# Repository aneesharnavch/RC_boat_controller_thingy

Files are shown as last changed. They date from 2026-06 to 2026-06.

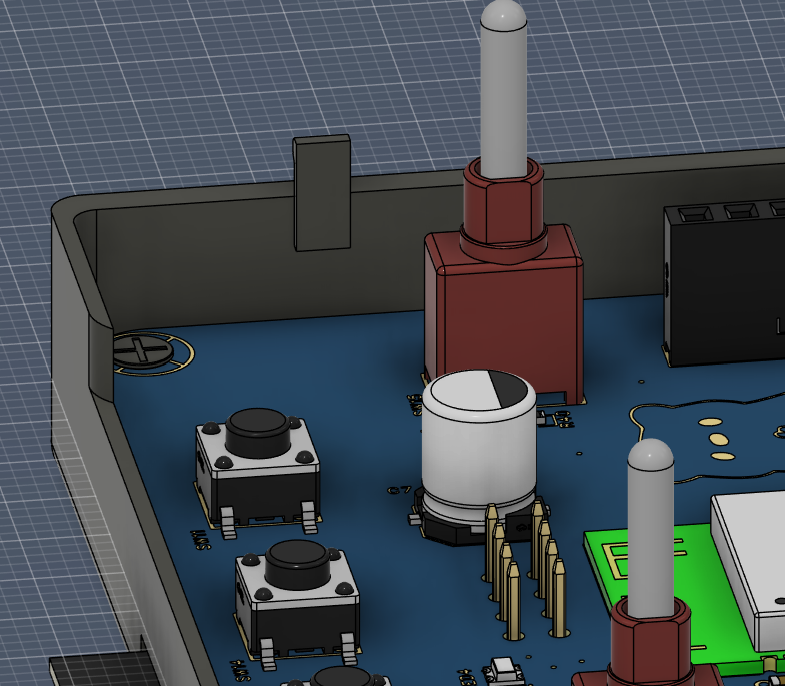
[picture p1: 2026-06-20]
Assets/controller_screw_assembly.png

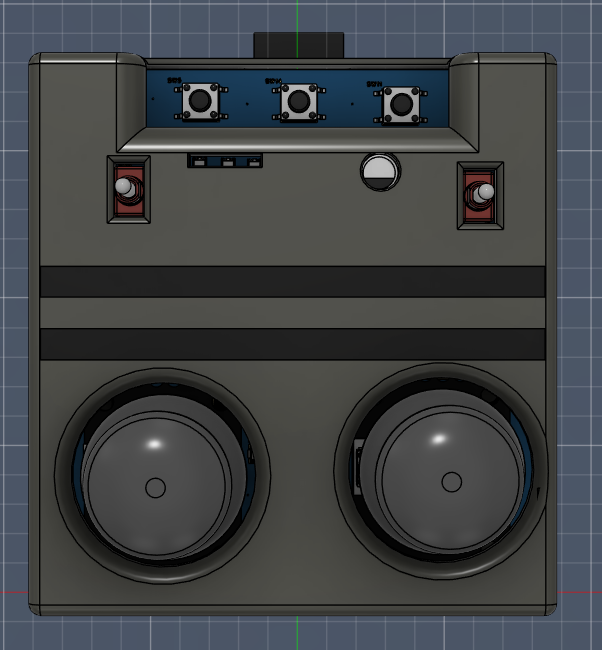
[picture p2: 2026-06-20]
Assets/controller_front.png

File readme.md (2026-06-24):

# RC Boat Thingy - an RC boat that goes WROOM WROOM   

title_pic

A Boat controller with an **IMU**, **Gyro** and **GPS** packed into a 3D-printed hull, powering an **ESC** and a **BLDC** motor. Along with it is a small controller that controls the boat over about a 2 km range.

# How does it work?

There's a simple RP2040-based controller IC that connects to all the electronics in the boat's hull. The controller then remotely connects to the receiver  and allows you to control its speed, direction, etc. When powered on and set up properly, the system works together to drive the propeller and move the boat across the water. 

# Why did I make it?

This was inspired by a boat my friends and I built back in the junior year of high school. While the initial idea we had back then worked in theory, the actual execution was.... Let's just say less successful. Because the boat we made in 2023~2024 had no Gyro with just a lacklustre IMU, its stabilisation was non-existent, with it doing WROOM WROOM underwater (thank god transparent nail polish is waterproof)

"RC Boat Thingy" is basically our second attempt at doing it properly, but approaching it with actual electronics and an actual control system, so it's actually controllable and usable without turning it into a submarine

# Components Required for the Build

| No. | Quantity | Description | Supplier | Supplier Part | Product Link | Cost | Total (USD) |
| --- | --- | --- | --- | --- | --- | --- | --- |
| 1 | 6 | 1x1 2.54mm pins for testing and troubleshooting | LCSC | C7501259 | https://www.lcsc.com/product-detail/C7501259.html | 0.015  | 0.09 |
| 2 | 1 | 1x6 2.54mm pins for connecting the ESC to the Controller | LCSC | C34498 | https://www.lcsc.com/product-detail/C34498.html | 0.51 | 0.51 |
| 3 | 1 | 1x4 2.54mm pins for SWD Branch out Header | LCSC | C2935929 | https://www.lcsc.com/product-detail/C2935929.html | 0.035  | 0.035 |
| 4 | 2 | BOOT and RESET buttons for the RP2040 | LCSC | C918859 | https://www.lcsc.com/product-detail/C918859.html | 0.2275 | 0.455 |
| 5 | 8 | 2.2uF 0603 Capacitors | LCSC | C23630 | https://www.lcsc.com/product-detail/C23630.html | 0.0093 | 0.0744 |
| 6 | 25 | 100nF 0603 Capacitors | LCSC | C191538 | https://www.lcsc.com/product-detail/C191538.html | 0.0122 | 0.305 |
| 7 | 2 | 15pF 0603 Capacitor | LCSC | C107037 | https://www.lcsc.com/product-detail/C107037.html | 0.0046 | 0.0092 |
| 8 | 1 | Antenna Connector for GPS Module | LCSC | C88374 | https://www.lcsc.com/product-detail/C88374.html | 0.108  | 0.108 |
| 9 | 1 | 33nH Inductor for GPS Antenna | LCSC | C90209 | https://www.lcsc.com/product-detail/C90209.html | 0.0134 | 0.0134 |
| 10  | 1 | LDO for RP2040 Battery to MC Power Rail | LCSC | C82942 | https://www.lcsc.com/product-detail/C82942.html | 0.51 | 0.51 |
| 11  | 1 | 0603 Red LED | LCSC | C84263 | https://www.lcsc.com/product-detail/C84263.html | 0.0095 | 0.0095 |
| 12  | 1 | 0603 Blue LED | LCSC | C965799 | https://www.lcsc.com/product-detail/C965799.html | 0.0035 | 0.0035 |
| 13  | 1 | Diode for LDO current Regulation | LCSC | C20512 | https://www.lcsc.com/product-detail/C20512.html | 0.0614 | 0.0614 |
| 14  | 5 | 1KΩ 0603 Resistor | LCSC | C22548 | https://www.lcsc.com/product-detail/C22548.html | 0.0016 | 0.008 |
| 15  | 1 | 470Ω 0603 Resistor | LCSC | C114669 | https://www.lcsc.com/product-detail/C114669.html | 0.0018 | 0.0018 |
| 16  | 1 | 200KΩ 0603 Resistor | LCSC | C105574 | https://www.lcsc.com/product-detail/C105574.html | 0.0016 | 0.0016 |
| 17  | 1 | 100KΩ 0603 Resistor | LCSC | C14675 | https://www.lcsc.com/product-detail/C14675.html | 0.0014 | 0.0014 |
| 18  | 1 | 200Ω 0603 Resistor | LCSC | C114664 | https://www.lcsc.com/product-detail/C114664.html | 0.0016 | 0.0016 |
| 19  | 1 | 1Ω 0603 Resistor | LCSC | C112305 | https://www.lcsc.com/product-detail/C112305.html | 0.0042 | 0.0042 |
| 20  | 6 | 10KΩ 0603 Resistor | LCSC | C965184 | https://www.lcsc.com/product-detail/C965184.html | 0.0032 | 0.0192 |
| 21  | 2 | 27Ω 0603 Resistor | LCSC | C25190 | https://www.lcsc.com/product-detail/C25190.html | 0.0015 | 0.003 |
| 22  | 4 | 5.1KΩ 0603 Resistor | LCSC | C23186 | https://www.lcsc.com/product-detail/C23186.html | 0.0016 | 0.0064 |
| 23  | 2 | 4.7KΩ 0603 Resistor | LCSC | C99782 | https://www.lcsc.com/product-detail/C99782.html | 0.0015 | 0.003 |
| 24  | 1 | RP2040 Microcontroller | LCSC | C2040 | https://www.lcsc.com/product-detail/C2040.html | 0.95 | 0.95 |
| 25  | 1 | W25Q128JVSIQ Flash Memory | LCSC | C97521 | https://www.lcsc.com/product-detail/C97521.html | 2.64 | 2.64 |
| 26  | 1 | 12MHz 10pF Crystal Oscillator | LCSC | C5288803 | https://www.lcsc.com/product-detail/C5288803.html | 0.59 | 0.59 |
| 27  | 1 | BMP388 Digital Pressure Sensor | LCSC | C779278 | https://www.lcsc.com/product-detail/C779278.html | 2.37 | 2.37 |
| 28  | 1 | M216Z-D80 GPS Module | LCSC | C49286686 | https://www.lcsc.com/product-detail/C49286686.html | 5.09 | 5.09 |
| 29  | 1 | USB C connector | LCSC | C2765186 | https://www.lcsc.com/product-detail/C2765186.html | 0.0704 | 0.0704 |
| 30  | 1 | RICHTEK RT9080-33GJ5(REGULARTOR FOR USB C | LCSC | C841192 | https://www.lcsc.com/product-detail/C841192.html | 0.1182 | 0.1182 |
| 31  | 1 | RED LED 0805 | LCSC | C84256 | https://www.lcsc.com/product-detail/C84256.html | 0.0134 | 0.0134 |
| 32  | 2 | BOOT AND RESET SWITCHES FOR THE CONTOLER | LCSC | C720477 | https://www.lcsc.com/product-detail/C720477.html | 0.054  | 0.108 |
| 33  | 1 | FLIP SWITCHES FOR CONTOLER | LCSC | C908284 | https://www.lcsc.com/product-detail/C908284.html | 1.664  | 1.664 |
| 34  | 3 | TACT BUTTON FOR CONTOLER | LCSC | C455118 | https://www.lcsc.com/product-detail/C455118.html | 0.0581 | 0.1743 |
| 35  | 1 | CAPASITOR FOR CONTORLER | LCSC | C72522 | https://www.lcsc.com/product-detail/C72522.html | 0.0221 | 0.0221 |
| 36  | 3 | LED for controller | LCSC | C965560 | https://www.lcsc.com/product-detail/C965560.html | 0.55 | 1.65 |
| 37  | 3 | USB C backwards current diode | LCSC | C41409280 | https://www.lcsc.com/product-detail/C41409280.html | 0.0243 | 0.0729 |
| 38  | 2 | Joystick | ElectroPi  | EPI7882 | https://www.electropi.in/dual-axis-xy-joystick-module | 0.29 | 0.58 |
| 39  | 2 | NRF24L01 Receiver and Transmitter | makerBazar | SKU:422942410 | https://makerbazar.in/products/2-4ghz-nrf24l01-pa-lna-sma-wireless-transceiver-antenna | 1.54 | 3.08 |
| 40  | 1 | IMU & Accelerometer Sensor | robu | SKU: R184320  | https://robu.in/product/icm-20948-tdk-invensense | 14.19  | 14.19 |
| 41  | 1 | Boat Controller PCB | JLCPCB | NA | https://cart.jlcpcb.com/quote | 1.3 | 1.3 |
| 42  | 1 | Transmitter PCB | JLCPCB | NA | https://cart.jlcpcb.com/quote | 1.3 | 1.3 |
| | | | | | | Total  | 38.2179 |

You can find the BOM in the repo as well!

# PCB and Schematic

I designed it in EasyEDA Pro. You can find the Gerber files in the repo. The schematic is:

The primary Boat Controller has the following schematics and PCBs:

schematic_board
pcb_board

The Transmitter has the following schematics and PCBs:

schematic_controller
pcb_controller

# Case

The Control Board is meant to be a fully tunable board with different motor control profiles based on the boat's dimensions. 

The transmitter needs its own case with its CAD files mentioned in the CAD_Files folder. 
The top and bottom view of the total transmitter assembly is attached below. 

controller_front

controller_back

controller_internal

The case features a snap-fit design, so you just have to like align the top and bottom parts of the 3D print together and press them together. You only need screws to screw the PCB into place with the bottom part.

controller_screw_assembly

# Assembly

Please do note that these assembly instructions are not final and can change. I've yet to build it, and when I do, I'll update this section to be more accurate. In the meanwhile, don't be afraid to change things up or make use of the several exposes GPIO pins/testing pad to make any modifications you would like to make. 

Note : Soldering Instructions are SUGGESTIONS and are typically personal preference , If your used to doing things a certain way , do not change it. I personally tend to do SMD components close to THT components first , followed by the THT components . 

1. Get the parts and PCB (It would be preferred if you get an SMD stencil to make assembly much easier using a hot air or an hotplate )
2. Start my soldering the components near the USB C connector (the diodes and decoupling capacitors) , Specifically for the boat controller you can solder R19, R18, C1, C2, C3, C4 and LDO1 followed by C1, D1, D2, D3, R1, R2 ,U4, C2, R5 on the transmitter PCB. You can solder the USB C connector now on both the PCB's 
3. Solder the RP2040 and ESP32 IC's on each of their respective boards, use a hot air or hotplate setup to reflow the solder with relative ease and BE GENEROUS WITH THE GND PAD SOLDER. 
4. From here on out, the order doesn't really matter as long as you can solder all of the components at their respective places as the BOM instructs you to do. All parts for this reason are 0603 or higher to make hand soldering a viable plan if your brave enough to approach doing so. Also , be generous with flux while soldering, it literally cant hurt (most of the times at least)
5. Inspect everything with your eyes , looking at every component individually. Its recommended to use an Multimeter or an LCR meter to just sanity check all of the values and check for continuity on all of your passives.
6. Use some Isopropanol to clean the Flux and solder residue off the board and connect it to a power source to make sure it doesn't explode.
7. Connect both of the boards to 5V of power and use a multimeter to check for signal continuity and voltage stability on the 5V , 3.3V , 1.1V test pads. 

# Hardware at a Glance 

| | Transmitter | Boat Controller |
| --- | --- | --- |
| MCU/Core | ESP32-S3 class board, Arduino-ESP32 core | RP2040, Earle Philhower arduino-pico core |
| Radio | nRF24L01(+) on SPI | nRF24L01(+) on SPI |
| Role | PTX (sends, stopListening()) | PRX (listens, startListening()) |
| Inputs | 2 joysticks, 2 push buttons, joystick switches | - |
| Outputs | 3× WS2812B status LEDs | rudder servo + ESC/BLDC motor |
| Sensors | - | ICM-20948 IMU, BMP388 baro, GPS |
| USB Serial | 115200 baud (status log) | 115200 baud (telemetry + serial commands) |

# Setting up the Boat Controller Software

Boat controller software setup :- 
1. Plug the Boat Controller board into your device first and hopefully it should show up as a "RPI-RP2 USB Device" or just another "USB Host Device". Either ways, once you've validated that your PC at least recognizes the board , head onto the next step 
2. Make sure to install all of the dependencies for the software mentioned in the dependencies.txt file to ensure the code runs and doesn't break down mid compilation
3. Reconnect the boat controller with the BOOT button held down to enter in BOOTSEL mode
4. Your computer should recognize the board as a USB mass storage device and will typically be named "RPI-RP2" 
5. All of the code being uploaded to the boat controller will be done so through the Arduino IDE, henceforth please make sure to add the RP2040 as an additional board. (go to File -> Preferences -> Additional Board Manager URLs -> Add this URL"https://github.com/earlephilhower/arduino-pico/releases/download/global/package_rp2040_index.json"
6. Go to Boards manager and search for RP2040, if there's any compatibility issues than install "Raspberry Pi Pico/RP2040/RP2350" by Earle F. Philhower
7. Before uploading the sketch provided in the Boat-Controller Firmware, configure your boat profile based on the  size and dimensions of your boat chassis. Run the python script the tools folder and take the files you get from that and dump them into the Firmware folder before proceeding to upload it to the board. 
8. Change the default nRF24L01 pin number to the GPIO's you have connected your module to and update the code accordingly
9. Upload the code with all of the changes accordingly and proceed to setup the transmitter.

# Transmitter pin map 
| Pin Name | name in code | GPIO | Notes |
|---|---|---|---|
| nRF CE | PIN_NRF_CE | 4 | |
| nRF CSN | PIN_NRF_CSN  | 5 | |
| nRF MISO | PIN_NRF_MISO | 6 | |
| nRF SCK | PIN_NRF_SCK  | 12 | |
| nRF MOSI | PIN_NRF_MOSI | 13 | |
| nRF IRQ | PIN_NRF_IRQ  | 14 | input only; not used by the polling driver |
| Joystick 1 X  | PIN_VRX1 | 1 | |
| Joystick 1 Y  | PIN_VRY1 | 2 | throttle |
| Joystick 1 SW | PIN_SW1 | 21 | latching KILL toggle |
| Joystick 2 X  | PIN_VRX2 | 3 | steering |
| Joystick 2 Y  | PIN_VRY2 | 36 | declared, currently unused |
| Joystick 2 SW | PIN_SW2 | 11 | currently unused |
| Status LEDs | PIN_LED | 48 | 3× WS2812B (NUM_LED = 3) |

# Setting up the Transmitter Software

Boat controller software setup :- 
1. Plug the Boat Controller board into your device first and hopefully it should show up as a "Silicon Labs CP210x USB to UART Bridge" or "FTDI USB Serial Converter". Either ways, once you've validated that your PC at least recognizes the board , head onto the next step 
2. Add the ESP32 boards core to the Arduino IDE , File → Preferences → Additional  
   Boards Manager URLs*, add:
   ```

   https://espressif.github.io/arduino-esp32/package_esp32_index.json

   ```
   
   Then *Tools → Board → Boards Manager…*, search **esp32** (by Espressif Systems) and install it.
  
3. Install the required libraries 

| Library | Author | Used for |
| --- | --- | --- |
| RF24 | TMRh20 | nRF24L01 driver |
| Adafruit NeoPixel | Adafruit | status LEDs |
`SPI`, `nRF24L01.h` (bundled with RF24), along with `radio_protocol.h` (local file in this  
folder) needs no installation.
4. Set the Pins to match any Physical wiring youve done Open `Transmitter.ino`. The pin block near the top is the single place to edit if  your board is wired differently:
```cpp
// nRF24L01 on SPI

static const int PIN_NRF_CE = 4;
static const int PIN_NRF_CSN = 5;
static const int PIN_NRF_MISO = 6;
static const int PIN_NRF_SCK = 12;
static const int PIN_NRF_MOSI = 13;

// Sticks

static const int PIN_VRY1 = 2;
static const int PIN_VRX2 = 3;

// LEDs

static const int PIN_LED  = 48;
static const int NUM_LED  = 3;
```

On the ESP32-S3 the SPI pins are routed through the GPIO matrix, so any free GPIO works for SCK/MOSI/MISO/CE/CSN. (Different from the boat controller)
5.  Confirm the radio link contents match the boat (the boats radio link is governed by a very high security password by default, a list of the letters BOAT)
```cpp
static const uint8_t NRF_ADDRESS[5] = {'B','O','A','T','1',};
static const uint8_t NRF_RF_CHANNEL = 76;
#define NRF_PA_LEVEL RF24_PA_LOW
```
Data rate (RF24_250KBPS), auto-ack(true), and the static 15-byte packet is set in setup() and already should match the boat controller.
6. Compile the Sketch and Upload with the board settings according to the WROOM-MODULE soldered on.
 **At power-on, leave the steering stick centered and untouched The firmware
 auto-captures the steering center during the first 50 ms of boot (`gSteerCenter`). If you're holding the stick over at boot, that offset becomes the new "center." 
# Transmitter Setup and Connection 

-  Transmits at a fixed 50Hz (`TX_PERIOD_MS = 20`). Every frame is read into the `RadioCommandPacket`, fills the checksum **last**, and calls  `radio.write()` . There is a verification function that stores a Boolean state of the value (ack received?) is stored in `radio.write()`.
- A failsafe trips if it hears nothing for 500ms (`COMMAND_TIMEOUT_US`). 
- ARMS WITH THROTTLE , NOT A BUTTON. On boot, the transmitter forces throttle to set itself to  idle (`US_MIN = 1000`). It does not arm or change throttle settings without having seen both sticks at idle .
- Boats DIE , like very easily , a drone may or may not fly into the abyss but its Carbon Fiber so it may or may not break physically. A boat will torpedo itself into the water while containing a timebomb off a battery so there is a very important kill switch that is triggered by SW1. 
- **Buttons:** `PB0` cycles mode 0→1→2→3→0; `PB1` toggles the kill switch
- The modes and their respective purposes are

| Mode | Value | Behavior |
| --- | ----- | --- |
| MODE_MANUAL | 0 | raw throttle + steering passthrough |
| MODE_ASSISTED | 1 | steering becomes a yaw rate command to like it wont accelerate into the void |
| MODE_HEADING_HOLD | 2 | holds headingDeg via a simple PID algorithm |
| MODE_COURSE_HOLD  | 3 | holds GPS location |
- The LED Key is : 

| LED | Meaning |
| ----- | --- |
| LED 0 | red = killed , Orange = arming , green= linked , pink = not linked |
| LED 1 | current mode colour : green/cyan/amber/purple for modes 0-3 |
| LED 2 | throttle level (brightness increases with throttle) |

### The packet (shared `radio_protocol.h`, 15 bytes, little-endian)
```cpp
struct_attribute_((packed)) RadioCommandPacket {

  uint16_t magic;     
  uint16_t seq;       
  uint16_t throttleUs; 
  uint16_t steeringUs;  
  uint16_t headingDeg;  
  uint16_t speedCmps;    
  uint8_t  mode;        
  uint8_t  flags;        
  uint8_t  checksum;  
}
```

- MAKE SURE BOTH ENDS MATCH , one link mismatches and the link dies
**[TX] `Transmitter.ino`:**
```cpp
static const uint8_t NRF_ADDRESS[5] = {'B','O','A','T','2'};  // new address
static const uint8_t NRF_RF_CHANNEL = 90;                     // new channel (0..125)
```
**[BOAT CONTROLLER] `Boat_Controller/config.h`:**
```cpp
static constexpr uint8_t NRF_RF_CHANNEL = 90;                       // <-- match
static constexpr uint8_t NRF_ADDRESS[5] = {'B','O','A','T','2'};   // <-- match
```

- If throttle or steering runs backwards, flip it in **one** place only
**[TX] `Transmitter.ino`:**
```cpp
static const bool INVERT_THROTTLE = true; // bottom of travel now = 1000us
static const bool INVERT_STEERING = true;
```

# Pairing the transmitter and the boat controller for the first time 

- Make sure all of the settings mentioned below are the same or tuned similar to the table. 

| Setting | Transmitter | Boat Controller |
|---|---|---|
| Channel | NRF_RF_CHANNEL = 76 | NRF_RF_CHANNEL = 76 |
| Address | {'B','O','A','T','1'} | {'B','O','A','T','1'} |
| Data rate | RF24_250KBPS | RF24_250KBPS |
| Payload | 15 bytes | 15 bytes |
| Pins | TX(2,3) | Boat wiring (4,6) |
- Power the boat controller and the transmitter and open both of their serial monitor at 115200 baud rate
- Let the firmware do its thing and pray to god its pairs (give it like a good minute of two) 
-  confirm pairing status based on LED0 status (Green is linked , Orange is Arming. Anything else is probably an issue waiting to happen or one that has already happen ) 
- Before arming let the GPS get a tower hit, It may take a while for the first time but it should blink a solid red once it has connected. 
- Let it Arm by moving joystick one away from throttle after waiting for 2.5S (the minimum link to ARM time differential)
# Code Tweaks / Example implementation 

Each snipped contains info on what file to edit and what to edit in that particular file.
Usually labeled either as :
`[TX]` = transmitter  (`Transmitter.ino`) or as `[BOAT_CONTROLLER]` = boat (`Boat_Controller/…`).

**[TX] `Transmitter.ino`:**
```cpp
static const uint8_t NRF_ADDRESS[5] = {'B','O','A','T','2'};  // new address
static const uint8_t NRF_RF_CHANNEL = 90;                     // new channel (0..125)
```
**[BOAT CONTROLLER] `Boat_Controller/config.h`:**
```cpp
static constexpr uint8_t NRF_RF_CHANNEL = 90;                       // <-- match
static constexpr uint8_t NRF_ADDRESS[5] = {'B','O','A','T','2'};   // <-- match
```

Pick a channel away from busy 2.4 GHz Wi-Fi. Channels ~70–125 (≈2.470–2.525 GHz)  are usually quieter. Address is 5 bytes; both arrays must be identical.

`Adjusting Steering center/deadband`
**[TX] `Transmitter.ino`** — the dead band (how far off-center before the rudder  
reacts) is a constant:
```cpp
static const int STEER_DEADBAND = 60;   // ADC counts; bigger = larger dead zone
```
The center is auto-captured at boot from the resting stick. To hard-code a fixed  center instead (e.g. a mechanically off-center pot), replace the auto-cal block in  `setup()`:
```cpp
// Instead of sampling PIN_VRX2 at boot: 
gSteerCenter = 1980; // your measured resting ADC value (0. .4095)
```

`Changing the transmit rate`
**[TX] `Transmitter.ino`:**
```cpp
static const uint32_t TX_PERIOD_MS = 10;//measured resting ADC value (0. .4095)
```
Keep it well under the boat's 500 ms timeout. Faster than ~100 Hz buys little and  
can cost ack reliability. If you ever raise the boat's `COMMAND_TIMEOUT_US`,  
recompute your minimum safe rate.

`Change the kill-switch behaviour wired to joystick-1 click`
The firmware ships with a Latching kill switch on SW1 - in this block in loop():
```cpp
if (buttonPressed(btnSW1)) {            // joystick-1 click = kill toggle
  gKill = !gKill;                       // click to kill, click again to release
  Serial.printf("[TX] kill -> %d\n", gKill);
}
```
if you want to set up a momentary dead-man switch where "held = killed , released = live", you can replace that block with a direct level read: 
```cpp
gKill = (digitalRead(PIN_SW1)==LOW); // pressed (LOW) = kill , release = live
```
Either way, `gKill` forces transmitted throttle to idle and sets `RADIO_FLAG_KILL`;  
the boat releases the kill as soon as it receives a packet with the bit cleared, and  
re-arms once you hold idle throttle again.

`BOAT increase boat speed/change rudder throw`
**Rudder throw and ESC idle/limits  `Boat_Controller/config.h`** (used by  `actuator.cpp`):
```cpp
static constexpr int SERVO_MAX_DEFLECT_US = 340;
static constexpr int ESC_US_IDLE = 1100;
static constexpr int ESC_US_MAX = 2000;
```

`Throttle Scaling (used by radio.cpp's bp_shape_throttle():`

```cpp
#define BP_THROTTLE_SCALE 0.30f // caps effective throttle at 30%ish here 
```

`Send a Speed hold target from the transmitter :`
`speedCmps` is in cm/s and runs as function only when >0 and the boat has a GPS fix.
**[TX] `Transmitter.ino`**, in `loop()`
```cpp
uint16_t spd = (uint16_t)((long)readAdcAvg(PIN_VRY2) * 300 / ADC_MAX);
p.speedCmps = spd; //eg 100 == 1m/s
```
**[BOAT_CONTROLLER]** ensure `ENABLE_SPEED_HOLD = true` and `USE_GPS = true` in `config.h`.

`PID assist modes and tuning :`
control.cpp at boot:

```cpp
static constexpr float PID_HEADING_KP = 2.00f	// turning sensitivity 
static constexpr float PID_HEADING_KI = 0.05f
static constexpr float PID_HEADING_KD = 0.05f

static constexpr float PID_YAWRATE_KP = 2.5f // no clue what it means , example sketch said you just tune this off running it multiple times
static constexpr float PID_SPEED_KP = 0.50f  // GPS speed threshold
```

# Settings up the Transmitter case 

Put the PCB into the bottom case aligning it with the screw holes , then screw in two M3 Phillips screws, make sure you dont screw it in too deep as it may thread the bottom out but screw them in till the board feels just secured, Now put the Top part of the case on and you should be done.
![[Pasted image 20260618032216.png]]

# Files

```cmd
RC_Boat_Thingyy:.
├───Assets
│       controller_back.png
│       controller_front.png
│       controller_internal.png
│       controller_screw_assembly.png
│       pcb_board.png
│       pcb_controller.png
│       schematic_board.png
│       schematic_controller.png
│
├───CAD_Files
│       RCBoatThingy.f3z
│       RCBoatThingy.step
│       RCBoatThingy_Transmitter.f3z
│       RCBoatThingy_Transmitter.step
│
├───Firmware
│   ├───Boat Controller
│   │       actuator.cpp
│   │       actuator.h
│   │       Boat_Controller.ino
│   │       boat_profile.c
│   │       boat_profile.h
│   │       commands.cpp
│   │       commands.h
│   │       config.h
│   │       control.cpp
│   │       control.h
│   │       CONTROLLER_HANDOVER.md
│   │       estimator.cpp
│   │       estimator.h
│   │       failsafe.cpp
│   │       failsafe.h
│   │       radio.cpp
│   │       radio.h
│   │       radio_protocol.h
│   │       readme.md
│   │       sensors.cpp
│   │       sensors.h
│   │       telemetry.cpp
│   │       telemetry.h
│   │       types.h
│   │
│   └───Transmitter
│           radio_protocol.h
│           Transmitter.ino
│
└───PCB_Files
        PickAndPlace_Board.xlsx
        PickAndPlace_Transmitter.xlsx
        RCBoatThingy_Gerber_Board.zip
        RCBoatThingy_Gerber_Transmitter.zip
        Source_Boat-Board.epro
        Source_Boat_Transmitter.epro
```

# Zine 
Zine_RC_Boat_Thingy

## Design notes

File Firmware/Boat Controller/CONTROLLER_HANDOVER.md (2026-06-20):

# Controller / Transmitter Handover

**Purpose:** everything needed to build the **transmitter** (hand controller) that
drives the RC Boat Thingy over an nRF24L01 link. The boat-side (receiver)
firmware already exists and is described below. Your job, if you're the agent
reading this, is to build a transmitter that produces packets the boat accepts.

> The single most important rule: **the transmitter and the boat must agree
> byte-for-byte on the radio settings and packet layout.** The boat side is the
> source of truth. Match it exactly.

---

## 1. System overview (boat side)

The boat runs an RP2040 (Earle Philhower arduino-pico core) with this firmware
layout:

| File | Role |
|---|---|
| `Boat_Controller.ino` | Cooperative scheduler; runs sensor/control/telemetry/command tasks on fixed periods. |
| `config.h` | All tunables and pin assignments, including the nRF24 block. |
| `types.h` | Shared structs/enums (`CommandInput`, `Mode`, etc.). |
| `sensors.*` | ICM-20948 IMU, BMP388 baro, GPS. |
| `estimator.*` | Complementary-filter attitude + speed/alt fusion. |
| `control.*` | PID controllers (heading / yaw-rate / speed), output mixing. |
| `actuator.*` | Servo (rudder) + ESC (motor) drive, arming, slew limiting. |
| `failsafe.*` | Timeout/validity monitoring → failsafe state. |
| `commands.*` | **Serial** command parser (text protocol, for bench use). |
| `radio.*` | **nRF24L01** command receiver (what your transmitter talks to). |
| `radio_protocol.h` | **Shared wire format. Copy this file into your transmitter project.** |
| `boat_profile.h/.c` | Optional generated tuning profile (input shaping lives here). |

Commands from **either** the serial parser **or** the radio land in the same
`CommandInput gCmd` struct. The control loop is agnostic to the source. Your
transmitter only needs to care about the radio path.

The command task runs at **50 Hz** (`COMMAND_HZ` in `config.h`) and polls the
radio every cycle.

---

## 2. The radio link contract (MUST MATCH)

These are set on the boat in `radio.cpp` (`initRadio()`) and `config.h`. Your
transmitter must configure the RF24 identically, except where noted.

| Setting | Boat value | Notes |
|---|---|---|
| Library | RF24 by TMRh20 | Use the same library on both ends. |
| Data rate | `RF24_250KBPS` | Must match. |
| RF channel | `NRF_RF_CHANNEL = 76` | `config.h`; must match. 0–125. |
| Address (5 bytes) | `NRF_ADDRESS = {'B','O','A','T','1'}` | = `0x42 0x4F 0x41 0x54 0x31`. Must match. |
| Address width | 5 (RF24 default) | Don't change. |
| CRC | RF24 default (16-bit, enabled) | Leave default on both ends. |
| Auto-ack | `setAutoAck(true)` | Must match. |
| Payload | **static**, `setPayloadSize(15)` | Boat uses fixed 15-byte payload. **Do NOT enable dynamic payloads.** Send exactly 15 bytes. |
| PA level | `RF24_PA_LOW` | Does **not** need to match; tune per range/power. |
| Retries | `setRetries(5, 15)` | Matters for the *transmitter* (it's the sender). Use the same as a starting point. |
| Role | Boat = PRX (`startListening()`) | Transmitter = PTX. |

**Pipe / address direction:** the boat does `openReadingPipe(1, NRF_ADDRESS)`.
The transmitter must `openWritingPipe(NRF_ADDRESS)` with the **identical 5-byte
array**. With auto-ack, RF24 handles the ack pipe automatically — no extra setup.

The boat's nRF **pins** are user-set in `config.h` (`PIN_NRF_CE`, `PIN_NRF_CSN`,
`PIN_NRF_SCK`, `PIN_NRF_MOSI`, `PIN_NRF_MISO`, and `NRF_USE_SPI1`). Your
transmitter's pins are independent — wire it however you like and configure its
own RF24 accordingly. **Channel and address are the only things that must match,
not pins.**

---

## 3. Packet format

Defined in `radio_protocol.h`. **Copy that file into your transmitter project
verbatim** and build the packet with the same struct — that eliminates any
byte-order or padding mistakes. The struct is `__attribute__((packed))`,
**15 bytes**, sent raw, **little-endian** (both ends are little-endian MCUs).

```c
static constexpr uint16_t RADIO_MAGIC = 0xB0A7;

enum RadioFlag : uint8_t {
  RADIO_FLAG_ARM  = 1 << 0,   // 0x01
  RADIO_FLAG_KILL = 1 << 1,   // 0x02
};

struct __attribute__((packed)) RadioCommandPacket {
  uint16_t magic;        // offset 0  : must equal RADIO_MAGIC (0xB0A7)
  uint16_t seq;          // offset 2  : increment every frame
  uint16_t throttleUs;   // offset 4  : 1000..2000
  uint16_t steeringUs;   // offset 6  : 1000..2000
  uint16_t headingDeg;   // offset 8  : 0..359
  uint16_t speedCmps;    // offset 10 : target speed in cm/s (0 = off)
  uint8_t  mode;         // offset 12 : Mode enum 0..3
  uint8_t  flags;        // offset 13 : RadioFlag bits
  uint8_t  checksum;     // offset 14 : XOR of bytes [0..13]
};
```

### Field semantics

| Field | Range / units | Meaning |
|---|---|---|
| `magic` | `0xB0A7` | Constant sanity tag. Packets with any other value are dropped. |
| `seq` | 0..65535, wraps | Increment once per transmitted frame. Used for link-quality/telemetry; the boat does not require monotonicity. |
| `throttleUs` | 1000–2000 µs | RC-style pulse. **1000 = idle/stop, 2000 = full.** See §4 for shaping. |
| `steeringUs` | 1000–2000 µs | RC-style pulse. **1500 = center**, 1000 = full left, 2000 = full right (reverse handled boat-side). |
| `headingDeg` | 0–359 | Target compass heading; only used in `MODE_HEADING_HOLD`. |
| `speedCmps` | cm/s | Target speed; only used when > 0 **and** GPS has a fix. `0` disables speed hold. (e.g. 2.5 m/s → `250`). |
| `mode` | 0–3 | See enum below. Values outside 0–3 are ignored (mode unchanged). |
| `flags` | bitmask | `0x01` arm, `0x02` kill. |
| `checksum` | XOR | `radioChecksum()` over bytes 0..13. Boat drops packets that fail. |

### Mode enum (from `types.h`)

| Value | Mode | Behavior |
|---|---|---|
| 0 | `MODE_MANUAL` | Raw throttle + steering passthrough. |
| 1 | `MODE_ASSISTED` | Steering becomes a yaw-rate command (rate damping). |
| 2 | `MODE_HEADING_HOLD` | Holds `headingDeg` via PID. |
| 3 | `MODE_COURSE_HOLD` | Holds GPS course. |

### Checksum

```c
static inline uint8_t radioChecksum(const RadioCommandPacket &p) {
  const uint8_t *bytes = reinterpret_cast<const uint8_t *>(&p);
  uint8_t c = 0;
  for (size_t i = 0; i < sizeof(RadioCommandPacket) - 1; i++) c ^= bytes[i];
  return c;
}
```

Fill `checksum` **last**, after every other field is set.

---

## 4. How the boat interprets throttle/steering

The boat converts the µs pulses to normalized commands. **Send clean, standard
RC pulses (1000/1500/2000) and let the boat do the shaping** — do not pre-apply
expo/deadband on the transmitter, or it will be applied twice.

- **If `boat_profile.h` was generated** (the usual case): pulses run through
  `bp_shape_throttle()` / `bp_shape_steering()`, which apply the profile's
  **deadband, expo, reverse flags, and throttle scaling**. Centers/endpoints come
  from `BP_RC_MIN_US`/`BP_RC_MID_US`/`BP_RC_MAX_US` (default 1000/1500/2000).
- **If no profile exists** (fallback in `radio.cpp`): throttle = `(us-1000)/1000`
  clamped 0..1; steering = `(us-1500)/500` clamped -1..1.

Either way, the transmitter's job is just: **map sticks to 1000–2000 µs, throttle
bottom = 1000, steering center = 1500.**

---

## 5. Arming, kill, and failsafe (transmitter must respect these)

### ESC arming is throttle-based (automatic)
On boot the boat is `ARM_DISARMED`. Arming happens in `actuator.cpp`:
- It moves to `ARM_ARMING` only once throttle is at/near idle (≤ ~0.01).
- It holds zero throttle for `ESC_ARM_TIME_MS` (**2500 ms**), then becomes
  `ARM_ARMED`.
- If throttle is raised while disarmed, throttle is forced to 0.

**Transmitter requirement:** at startup, send **idle throttle (1000 µs)** and
wait ~3 s before commanding throttle. The `RADIO_FLAG_ARM` bit is currently
*informational* — arming is gated by idle throttle, not by the flag. (Set the
flag anyway; future firmware may consume it.)

### Kill
Setting `RADIO_FLAG_KILL` makes the boat latch failsafe (motor + steering zeroed,
disarmed). The boat re-reads the flag every packet, so **clearing the kill bit in
a later packet releases the kill** (you then re-arm via idle throttle). Design
your controller's kill switch with that in mind (e.g. momentary vs latching).

### Command-timeout failsafe (critical)
The boat triggers `FAIL_CMD_TIMEOUT` if no valid command arrives within
`COMMAND_TIMEOUT_US` = **500 ms** (`config.h`). On timeout the motor and steering
are zeroed.

**Transmitter requirement:** send packets continuously at a steady rate even when
nothing changes. **Recommended: 50 Hz** (matches the boat's command task; one
packet every 20 ms). Anything slower than 2 Hz will trip the failsafe. 20–50 Hz
is the sweet spot.

---

## 6. Reference transmitter logic

Pseudocode for a minimal correct transmitter (real Arduino/RF24 on any
little-endian MCU; RP2040, AVR, ESP32 all fine):

```c
#include <SPI.h>
#include <RF24.h>
#include "radio_protocol.h"   // copied from the boat project

const uint8_t ADDRESS[5] = {'B','O','A','T','1'};   // MUST match boat
RF24 radio(TX_CE_PIN, TX_CSN_PIN);                   // your wiring

uint16_t seq = 0;

void setup() {
  // (configure SPI pins for your board if needed)
  radio.begin();
  radio.setDataRate(RF24_250KBPS);   // match boat
  radio.setChannel(76);              // match boat NRF_RF_CHANNEL
  radio.setPayloadSize(sizeof(RadioCommandPacket));  // 15, static
  radio.setAutoAck(true);
  radio.setRetries(5, 15);
  radio.setPALevel(RF24_PA_LOW);     // tune for range
  radio.openWritingPipe(ADDRESS);
  radio.stopListening();             // PTX role
}

void loop() {
  RadioCommandPacket p = {};
  p.magic      = RADIO_MAGIC;
  p.seq        = seq++;
  p.throttleUs = readThrottleStick_1000_2000();   // 1000 at rest!
  p.steeringUs = readSteeringStick_1000_2000();    // 1500 center
  p.headingDeg = currentTargetHeading();           // 0..359 (or 0)
  p.speedCmps  = currentTargetSpeedCmps();         // 0 to disable
  p.mode       = currentMode();                    // 0..3
  p.flags      = (armSwitch ? RADIO_FLAG_ARM : 0)
               | (killSwitch ? RADIO_FLAG_KILL : 0);
  p.checksum   = radioChecksum(p);                 // last

  radio.write(&p, sizeof(p));

  delay(20);   // ~50 Hz; keep it steady to avoid the 500 ms failsafe
}
```

### Startup sequence the transmitter should enforce
1. Power on with throttle stick at idle (1000 µs).
2. Begin transmitting at 50 Hz immediately (idle throttle).
3. Hold idle ≥ 3 s so the boat's ESC arms.
4. Then allow throttle commands.

---

## 7. Boat-side values you can change (and must keep in sync)

If you edit these on the boat, mirror them on the transmitter:

| `config.h` constant | Default | Sync? |
|---|---|---|
| `NRF_RF_CHANNEL` | 76 | Yes — must match. |
| `NRF_ADDRESS` | `{'B','O','A','T','1'}` | Yes — must match. |
| `USE_NRF24` | `true` | If false, boat ignores the radio entirely. |
| `NRF_USE_SPI1` | `false` | Boat-local SPI bus choice; not shared. |
| `PIN_NRF_*` | placeholders | Boat-local wiring; not shared. **Set these to your boat's wiring.** |
| `COMMAND_TIMEOUT_US` | 500000 | If you raise/lower it, adjust min TX rate. |
| Data rate / PA / payload | in `radio.cpp` | Data rate + payload must match; PA need not. |

---

## 8. Gotchas

- **Don't enable dynamic payloads** on the transmitter — the boat uses a fixed
  15-byte payload. Mismatched payload handling = nothing received.
- **Checksum is filled last.** Compute it after all fields are set, or it'll be
  wrong and every packet will be silently dropped.
- **Throttle must idle at 1000 µs at startup**, or the ESC never arms.
- **Keep transmitting even when idle** — silence > 500 ms = failsafe.
- **Don't double-shape inputs.** Expo/deadband/reverse happen on the boat. Send
  linear 1000–2000 pulses.
- **Endianness/packing:** reuse `radio_protocol.h` and send the struct raw. Only
  hand-pack bytes if your TX MCU is big-endian (none of the common Arduino MCUs
  are) — in which case serialize each field little-endian explicitly.
- **Telemetry is one-way for now.** The boat prints telemetry over USB serial
  (see `telemetry.cpp`); it does **not** send telemetry back over the nRF link.
  If you want radio telemetry, that's a new feature on both ends (ack payloads or
  a second pipe) — not currently implemented.

---

## 9. File checklist for the transmitter project

- Copy **`radio_protocol.h`** from the boat firmware into the transmitter
  project. It is dependency-free (only `<stdint.h>`/`<stddef.h>`).
- Install the **RF24 (TMRh20)** library.
- Match **channel 76** and **address `{'B','O','A','T','1'}`**, `RF24_250KBPS`,
  static 15-byte payload, auto-ack on.
- Transmit `RadioCommandPacket` at ~50 Hz with a valid `magic` and `checksum`.

That's the entire contract. If the boat firmware's radio settings change, this
document and `radio_protocol.h` are the two things to re-check.

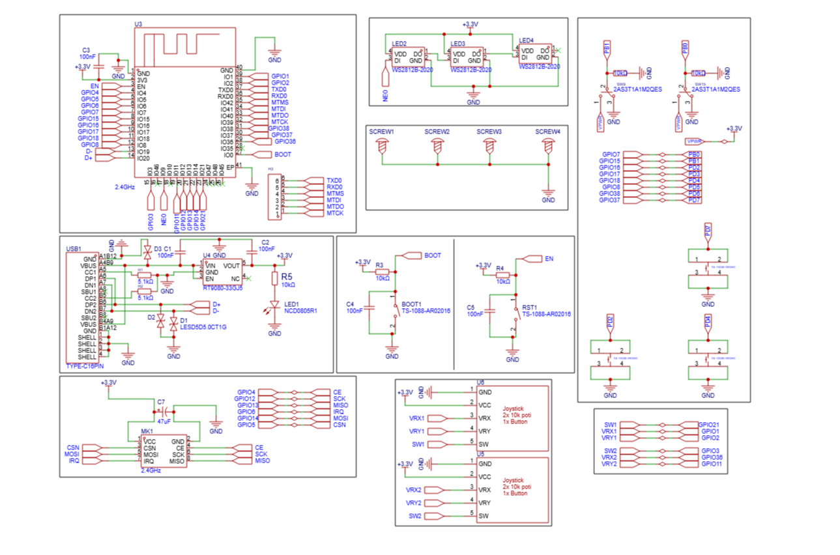
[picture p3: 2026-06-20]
Assets/schematic_controller.png

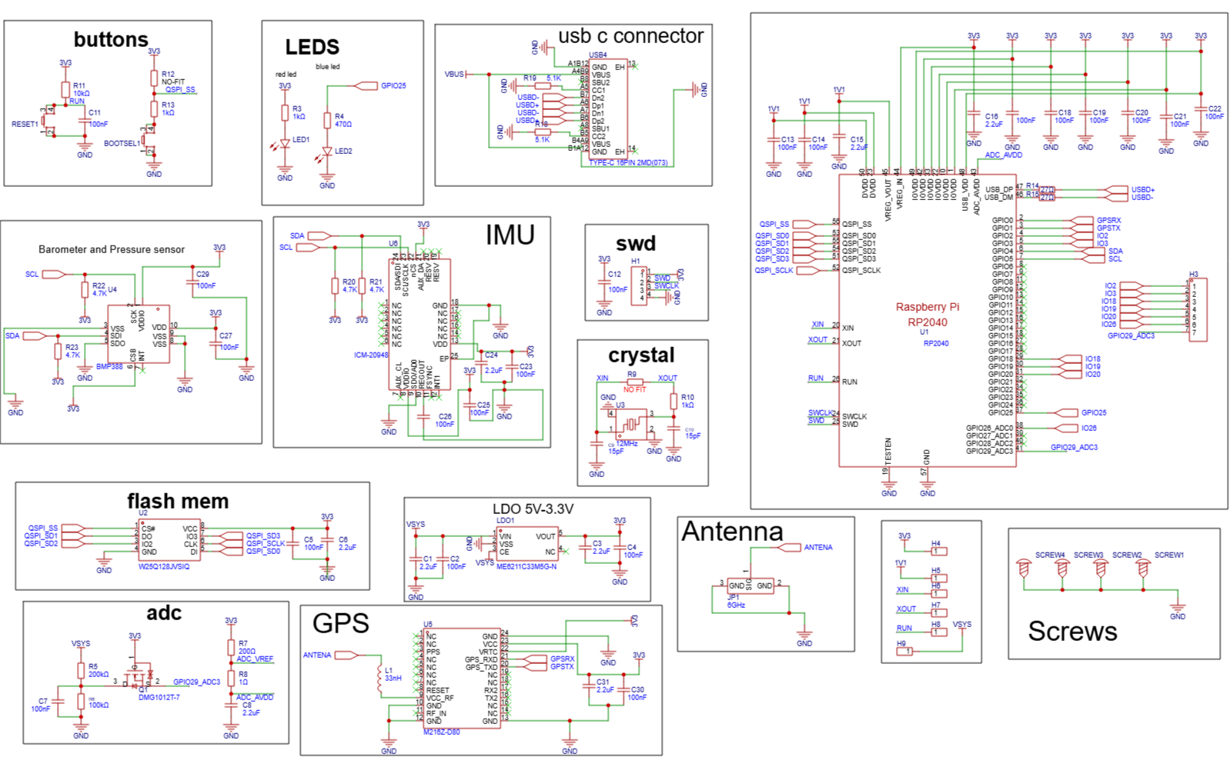
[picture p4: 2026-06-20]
Assets/schematic_board.png

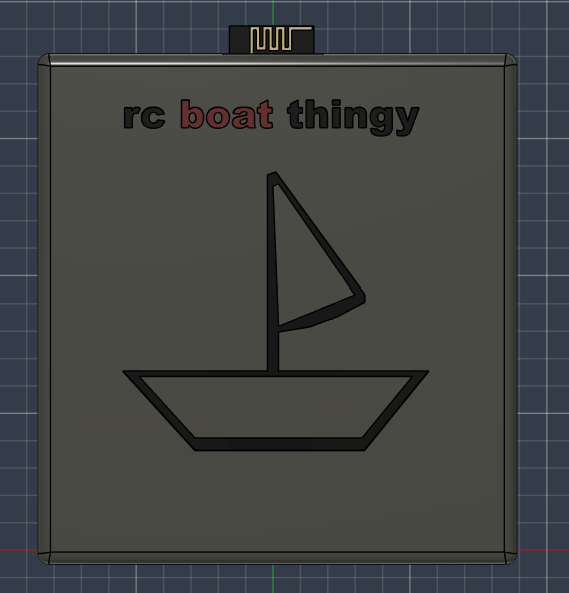
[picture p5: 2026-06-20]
Assets/controller_back.png

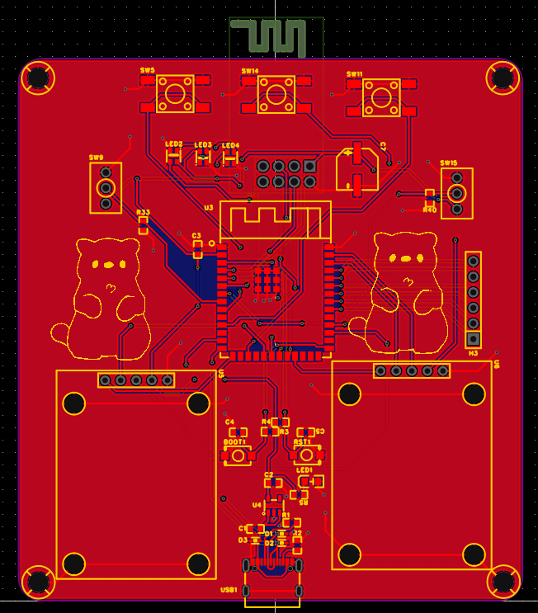
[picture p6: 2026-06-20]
Assets/pcb_controller.png

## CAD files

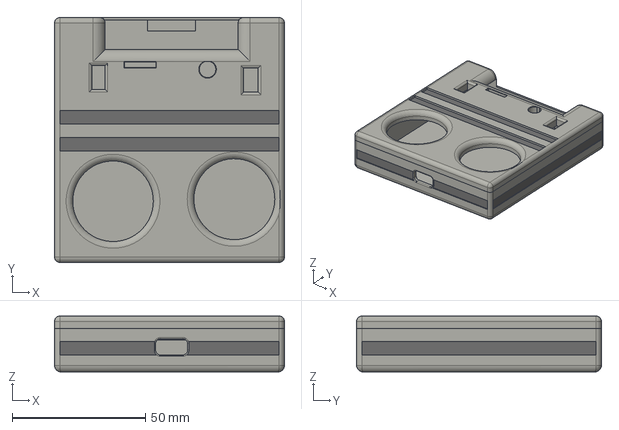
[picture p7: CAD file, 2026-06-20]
CAD_Files/Transmitter/RC_boat_thingyy_Transmitter_Fully_Assembled.step
86.4 x 92.0 x 21.0 mm

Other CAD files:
CAD_Files/Transmitter/RC_boat_thingyy_Transmitter_Fully_Assembled.f3z

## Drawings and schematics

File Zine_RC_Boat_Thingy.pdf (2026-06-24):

## IMU AND ACCELEROMETER

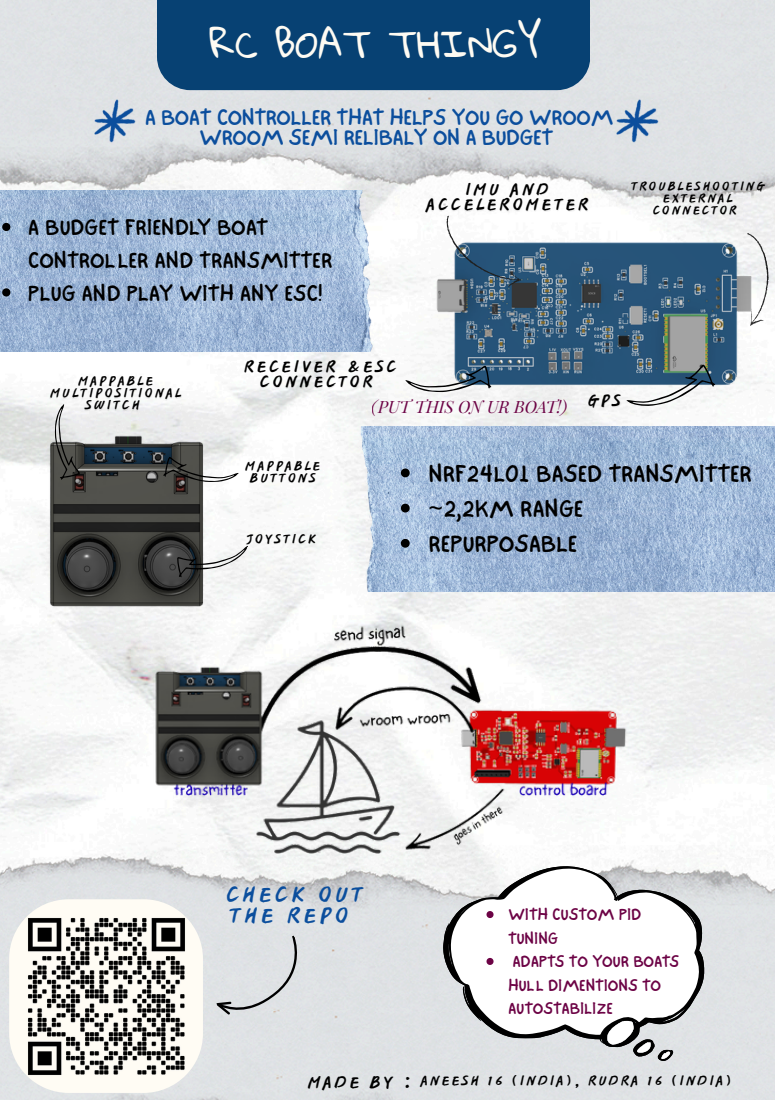
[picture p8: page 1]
JOYSTICK; MAPPABLE MULTIPOSITIONAL SWITCH; MAPPABLE BUTTONS; RECEIVER &ESC CONNECTOR; TROUBLESHOOTING EXTERNAL CONNECTOR; IMU AND ACCELEROMETER; CHECK OUT THE REPO

RC BOAT THINGY

A BOAT CONTROLLER THAT HELPS YOU GO WROOM
WROOM SEMI RELIBALY ON A BUDGET

A BUDGET FRIENDLY BOAT
CONTROLLER AND TRANSMITTER
PLUG AND PLAY WITH ANY ESC!

GPS RECEIVER &ESC
CONNECTOR

(PUT THIS ON UR BOAT!)
NRF24L01 BASED TRANSMITTER
~2,2KM RANGE
REPURPOSABLE

WITH CUSTOM PID
TUNING
ADAPTS TO YOUR BOATS
HULL DIMENTIONS TO
AUTOSTABILIZE

MADE BY : ANEESH 16 (INDIA), RUDRA 16 (INDIA)

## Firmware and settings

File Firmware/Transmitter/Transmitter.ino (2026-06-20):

#include <SPI.h>
#include <RF24.h>
#include <nRF24L01.h>
#include <Adafruit_NeoPixel.h>
#include "radio_protocol.h"

// defining pinouts 

static const int PIN_NRF_CE = 4;
static const int PIN_NRF_CSN = 5;
static const int PIN_NRF_MISO = 6;
static const int PIN_NRF_SCK = 12;
static const int PIN_NRF_MOSI = 13;
static const int PIN_NRF_IRQ = 14; 
// pin 14 is not actively used by the polling driver and is left as an input pin 

// Joystick 1
static const int PIN_VRX1 = 1;
static const int PIN_VRY1 = 2;
static const int PIN_SW1 = 21;

// Joystick 2 
static const int PIN_VRX2 = 3;
static const int PIN_VRY2 = 36;
static const int PIN_SW2 = 11; 

// Push Button (pulled up to 3.3V)
static const int PIN_PB0 = 15;
static const int PIN_PB1 = 7;

//WS2812B status LED 
static const int PIN_LED = 48;
static const int NUM_LED = 3; 

// CONNECTING RADIO THINGY , MUST MATCH BOAT PLEASE CHANGE ACCORDINGLY , WILL NOT WORK IF YOUVE CHANGED THE SLIGHTEST THINGY 
static const uint8_t NRF_ADDRESS[5] = {'B','O','A','T','1'};
static const uint8_t NRF_RF_CHANNEL = 76;
#define NRF_PA_LEVEL RF24_PA_LOW

// Time steps
static const uint32_t TX_PERIOD_MS = 20; 
static const uint32_t ARM_HOLD_MS = 3500;

// Stick callibration 
static const int ADC_MAX = 4095;
static const uint16_t US_MIN = 1000;
static const uint16_t US_MID = 1500;
static const uint16_t US_MAX = 2000; 
static const int STEER_DEADBAND  = 60;     

// Reverse switches 
static const bool     INVERT_THROTTLE = false;   // bottom of travel must = 1000us
static const bool     INVERT_STEERING = false;

// Global
RF24 radio(PIN_NRF_CE, PIN_NRF_CSN);
Adafruit_NeoPixel leds(NUM_LED, PIN_LED, NEO_GRB + NEO_KHZ800);
RadioCommandPacket p;

// first boot config settings 
uint16_t gSeq = 0;
int gSteerCenter = ADC_MAX / 2;  
uint8_t gMode = 0;                 
bool gArmFlag = false;             
bool gKill = false;   

// startup and arming gate , addingh buffer time when pinned at idle on the boats ESC
bool gArmGate = true;
uint32_t gBootMs = 0;
bool gSeenIdle = false;
bool gLinkOk = false;   
uint32_t gLastTxMs = 0;

// Button debounce 
struct Button {
  int      pin;
  bool     lastStable;     // true = released (HIGH)
  bool     lastRead;
  uint32_t lastChangeMs;
};

Button btnPB0{PIN_PB0, true, true, 0};
Button btnPB1{PIN_PB1, true, true, 0};
Button btnSW1{PIN_SW1, true, true, 0};

// Returns true on a press edge (released -> pressed)
bool buttonPressed(Button &b) {
  bool reading = digitalRead(b.pin);   // HIGH = released, LOW = pressed
  uint32_t now = millis();
  if (reading != b.lastRead) {
    b.lastRead = reading;
    b.lastChangeMs = now;
  }
  bool edge = false;
  if ((now - b.lastChangeMs) > 25) {   // 25ms debounce
    if (reading != b.lastStable) {
      b.lastStable = reading;
      if (reading == LOW) edge = true; // just pressed
    }
  }
  return edge;
}

// Joystick reading 
int readAdcAvg(int pin) {
  long acc = 0;
  for (int i = 0; i < 4; i++) acc += analogRead(pin);
  return (int)(acc / 4);
}

uint16_t readThrottleUs() {
  int raw = readAdcAvg(PIN_VRY1);
  if (INVERT_THROTTLE) raw = ADC_MAX - raw;
  long us = US_MIN + (long)raw * (US_MAX - US_MIN) / ADC_MAX;
  if (us < US_MIN) us = US_MIN;
  if (us > US_MAX) us = US_MAX;
  return (uint16_t)us;
}

uint16_t readSteeringUs() {
  int raw = readAdcAvg(PIN_VRX2);
  if (INVERT_STEERING) raw = ADC_MAX - raw;
  int delta = raw - gSteerCenter;
  if (delta > -STEER_DEADBAND && delta < STEER_DEADBAND) return US_MID;
  long us;
  if (delta >= 0) {
    long span = (ADC_MAX - gSteerCenter);
    if (span < 1) span = 1;
    us = US_MID + (long)(delta - STEER_DEADBAND) * (US_MAX - US_MID) / span;
  } else {
    long span = gSteerCenter;
    if (span < 1) span = 1;
    us = US_MID + (long)(delta + STEER_DEADBAND) * (US_MID - US_MIN) / span;
  }
  if (us < US_MIN) us = US_MIN;
  if (us > US_MAX) us = US_MAX;
  return (uint16_t)us;
}

// Status LEDs 
uint32_t modeColor(uint8_t m){
  switch (m){
    case 0: return leds.Color(0, 40, 0);    // MANUAL  - green
    case 1: return leds.Color(0, 30, 40);   // ASSISTED   - cyan
    case 2: return leds.Color(40, 25, 0);   // HEADING_HOLD - amber
    case 3: return leds.Color(30, 0, 40);   // COURSE_HOLD  - purple
  }
  return 0;
}

void updateLeds(uint16_t throttleUs) {
  if (gKill) leds.setPixelColor(0, leds.Color(60, 0, 0));      // red  = killed
  else if (gArmGate) leds.setPixelColor(0, leds.Color(50, 30, 0));    // amber= arming
  else if (gLinkOk) leds.setPixelColor(0, leds.Color(0, 50, 0));     // green= linked
  else leds.setPixelColor(0, leds.Color(50, 0, 30));    // pink = no ack
// led1 state
  leds.setPixelColor(1, modeColor(gMode));
// led2 throttle level 
  uint8_t lvl = (uint8_t)((long)(throttleUs - US_MIN) * 60 / (US_MAX - US_MIN));
  leds.setPixelColor(2, leds.Color(lvl, lvl, lvl));
  leds.show();
}

// setup 
void setup(){
  Serial.begin(115200);

  //button decleration 
  pinMode(PIN_PB0, INPUT_PULLUP);
  pinMode(PIN_PB1, INPUT_PULLUP);
  pinMode(PIN_SW1, INPUT_PULLUP);
  pinMode(PIN_SW2, INPUT_PULLUP);
  pinMode(PIN_NRF_IRQ, INPUT);

  // ADC 
  analogReadResolution(12);
  analogSetAttenuation(ADC_11db);

  //LEDS
  leds.begin();
  leds.clear();
  leds.show();

  // Capture steering center (assume stick released/centered at boot).
  delay(50);
  long acc = 0;
  for (int i = 0; i < 32; i++) { acc += analogRead(PIN_VRX2); delay(1); }
  gSteerCenter = (int)(acc / 32);

  // SPI on the controllers custom pins
  SPI.begin(PIN_NRF_SCK, PIN_NRF_MISO, PIN_NRF_MOSI, PIN_NRF_CSN);
  if (!radio.begin(&SPI)) {
    Serial.println(F("[nRF24] begin() FAILED - check wiring/power"));
  }
  radio.setDataRate(RF24_250KBPS);
  radio.setChannel(NRF_RF_CHANNEL);
  radio.setPayloadSize(sizeof(RadioCommandPacket));
  radio.setAutoAck(true);
  radio.setRetries(5, 15);
  radio.setPALevel(NRF_PA_LEVEL);
  // Dynamic payloads intentionally left OFF (default).
  radio.openWritingPipe(NRF_ADDRESS);
  radio.stopListening();

  gBootMs   = millis();
  gLastTxMs = gBootMs;

  Serial.println(F("[TX] Transmitter ready. Holding idle throttle for ESC arming..."));
  Serial.println(F("[TX] Pull throttle stick to the BOTTOM to complete arming."));

}

//  Main loop  (fixed 50 Hz cadence)
void loop(){
  uint32_t now = millis();
  if (buttonPressed(btnPB0)) {        // cycle mode
    gMode = (gMode + 1) & 0x03;
    Serial.printf("[TX] mode -> %u\n", gMode);
  }
  if (buttonPressed(btnPB1)) {                 // toggle arm flag
    gArmFlag = !gArmFlag;
    Serial.printf("[TX] arm flag -> %d\n", gArmFlag);
  }
  if (buttonPressed(btnSW1)) {                 // joystick-1 click = kill toggle
    gKill = !gKill;                            // latches RADIO_FLAG_KILL + forces idle throttle
    Serial.printf("[TX] kill -> %d\n", gKill);
  }

  if (now - gLastTxMs < TX_PERIOD_MS) return;  // hold 50 Hz
  gLastTxMs += TX_PERIOD_MS;
  if (now - gLastTxMs > TX_PERIOD_MS) gLastTxMs = now;  

  // read sticks 
  uint16_t rawThrottle = readThrottleUs();
  uint16_t steeringUs  = readSteeringUs();
  
  if (gArmGate) {
    if (rawThrottle <= US_MIN + 40) gSeenIdle = true;
    if (gSeenIdle && (now - gBootMs >= ARM_HOLD_MS)) {
      gArmGate = false;
      Serial.println(F("[TX] arming complete - throttle live"));
    }
  }

  uint16_t throttleUs = gArmGate ? US_MIN : rawThrottle;
  if (gKill) throttleUs = US_MIN;

  // make packet 
  p.magic = RADIO_MAGIC;
  p.seq = gSeq++;
  p.throttleUs = throttleUs;
  p.steeringUs = steeringUs;
  p.headingDeg = 0;        // populated only if a heading source is added
  p.speedCmps = 0;        // 0 = speed-hold disabled
  p.mode = gMode;
  p.flags = (gArmFlag ? RADIO_FLAG_ARM : 0) | (gKill    ? RADIO_FLAG_KILL : 0);
  p.checksum   = radioChecksum(p);   
  gLinkOk = radio.write(&p, sizeof(p));   // true if ack received

  updateLeds(throttleUs);
}

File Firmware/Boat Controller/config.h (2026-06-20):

#pragma once

#include <Arduino.h>

static constexpr uint32_t SERIAL_BAUD = 115200;
static constexpr uint32_t BOOT_DELAY_MS = 400;

static constexpr uint8_t PIN_I2C_SDA = 4;
static constexpr uint8_t PIN_I2C_SCL = 5;

static constexpr uint8_t PIN_SERVO_SIGNAL = 18;
static constexpr uint8_t PIN_ESC_SIGNAL = 19;

static constexpr uint8_t PIN_GPS_RX = 9;
static constexpr uint8_t PIN_GPS_TX = 8;
static constexpr uint32_t GPS_BAUD = 9600;

static constexpr uint8_t ICM20948_ADDR = 0x69;
static constexpr uint8_t BMP388_ADDR = 0x77;

// --------------------------
// nRF24L01 command radio
// --------------------------
// The nRF24L01 is an SPI device. CE and CSN can be ANY free GPIO; the
// SCK / MOSI / MISO pins MUST be valid pins for the SPI bus selected by
// NRF_USE_SPI1 below (RP2040 has fixed pin groups per SPI peripheral).
//
// >>> SET ALL FIVE PINS TO MATCH YOUR WIRING. The values below are only
// >>> placeholders that avoid clashing with the I2C/servo/GPS pins. <<<
static constexpr bool USE_NRF24 = true;
static constexpr bool NRF_USE_SPI1 = false;  // false = SPI0, true = SPI1

static constexpr uint8_t PIN_NRF_CE = 1;     // TODO: your wiring (any GPIO)
static constexpr uint8_t PIN_NRF_CSN = 7;    // TODO: your wiring (any GPIO)
static constexpr uint8_t PIN_NRF_SCK = 2;    // TODO: must be a SCK pin of the chosen SPI bus
static constexpr uint8_t PIN_NRF_MOSI = 3;   // TODO: must be a TX  pin of the chosen SPI bus
static constexpr uint8_t PIN_NRF_MISO = 0;   // TODO: must be a RX  pin of the chosen SPI bus

// RF link settings (must match the transmitter exactly).
static constexpr uint8_t NRF_RF_CHANNEL = 76;  // 0..125 (avoid common WiFi channels)
static constexpr uint8_t NRF_ADDRESS[5] = {'B', 'O', 'A', 'T', '1'};

static constexpr float IMU_HZ = 200.0f;
static constexpr float BARO_HZ = 25.0f;
static constexpr float GPS_HZ = 20.0f;
static constexpr float CONTROL_HZ = 100.0f;
static constexpr float TELEMETRY_HZ = 10.0f;
static constexpr float COMMAND_HZ = 50.0f;

static constexpr uint32_t IMU_PERIOD_US = static_cast<uint32_t>(1000000.0f / IMU_HZ);
static constexpr uint32_t BARO_PERIOD_US = static_cast<uint32_t>(1000000.0f / BARO_HZ);
static constexpr uint32_t GPS_PERIOD_US = static_cast<uint32_t>(1000000.0f / GPS_HZ);
static constexpr uint32_t CONTROL_PERIOD_US = static_cast<uint32_t>(1000000.0f / CONTROL_HZ);
static constexpr uint32_t TELEMETRY_PERIOD_US = static_cast<uint32_t>(1000000.0f / TELEMETRY_HZ);
static constexpr uint32_t CMD_PERIOD_US = static_cast<uint32_t>(1000000.0f / COMMAND_HZ);
static constexpr uint32_t HEARTBEAT_PERIOD_US = 250000;

// --------------------------
// Feature flags
// --------------------------
static constexpr bool USE_BMP388 = true;
static constexpr bool USE_GPS = true;
static constexpr bool USE_MAG_YAW = false;
static constexpr bool ENABLE_HEADING_HOLD = true;
static constexpr bool ENABLE_SPEED_HOLD = true;
static constexpr bool ENABLE_RATE_DAMPING = true;

// --------------------------
// Servo and ESC
// --------------------------
static constexpr int SERVO_US_MIN = 1100;
static constexpr int SERVO_US_CENTER = 1500;
static constexpr int SERVO_US_MAX = 1900;
static constexpr int SERVO_MAX_DEFLECT_US = 340;
static constexpr int SERVO_MAX_SLEW_US_PER_TICK = 10;

static constexpr int ESC_US_MIN = 1000;
static constexpr int ESC_US_IDLE = 1100;
static constexpr int ESC_US_MAX = 2000;
static constexpr int ESC_ARM_US = 1000;
static constexpr uint16_t ESC_ARM_TIME_MS = 2500;
static constexpr int ESC_MAX_SLEW_US_PER_TICK = 8;

// --------------------------
// Safety thresholds
// --------------------------
static constexpr float MAX_ABS_ROLL_DEG_FOR_FULL_THR = 35.0f;
static constexpr float MAX_ABS_PITCH_DEG_FOR_FULL_THR = 20.0f;
static constexpr float FAILSAFE_THROTTLE_FACTOR = 0.55f;

static constexpr uint32_t SENSOR_TIMEOUT_IMU_US = 120000;
static constexpr uint32_t SENSOR_TIMEOUT_BARO_US = 300000;
static constexpr uint32_t SENSOR_TIMEOUT_GPS_US = 1500000;
static constexpr uint32_t COMMAND_TIMEOUT_US = 500000;

// Estimator tuning

static constexpr float ACCEL_LPF_ALPHA = 0.24f;
static constexpr float GYRO_LPF_ALPHA = 0.30f;
static constexpr float BARO_LPF_ALPHA = 0.15f;
static constexpr float COMPLEMENTARY_ALPHA = 0.98f;

// PID tuning

static constexpr float PID_HEADING_KP = 2.00f;
static constexpr float PID_HEADING_KI = 0.06f;
static constexpr float PID_HEADING_KD = 0.03f;
static constexpr float PID_HEADING_I_LIM = 35.0f;
static constexpr float PID_HEADING_OUT_LIM = 45.0f;  // deg/s yaw target

static constexpr float PID_YAWRATE_KP = 2.60f;
static constexpr float PID_YAWRATE_KI = 0.25f;
static constexpr float PID_YAWRATE_KD = 0.02f;
static constexpr float PID_YAWRATE_I_LIM = 30.0f;
static constexpr float PID_YAWRATE_OUT_LIM = 1.0f;   // normalized steer
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

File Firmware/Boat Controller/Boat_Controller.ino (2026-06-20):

#include "config.h"
#include "types.h"
#include "sensors.h"
#include "estimator.h"
#include "actuator.h"
#include "control.h"
#include "failsafe.h"
#include "telemetry.h"
#include "commands.h"
#include "radio.h"

BoatState gState = {};
SensorFrame gSensors = {};
EstimatorState gEst = {};
CommandInput gCmd = {};
ControlOutput gOut = {};
FailsafeState gFail = {};

static uint32_t lastImuUs = 0;
static uint32_t lastBaroUs = 0;
static uint32_t lastGpsUs = 0;
static uint32_t lastCtlUs = 0;
static uint32_t lastTelUs = 0;
static uint32_t lastCmdUs = 0;
static uint32_t lastHeartbeatUs = 0;

static void runImuTask(uint32_t nowUs) {
  float dt = (lastImuUs == 0) ? (1.0f / IMU_HZ) : ((nowUs - lastImuUs) * 1e-6f);
  lastImuUs = nowUs;

  updateImu(gSensors, gState, nowUs);
  updateEstimatorFromImu(gSensors, gEst, gState, dt);
}

static void runBaroTask(uint32_t nowUs) {
  lastBaroUs = nowUs;
  updateBaro(gSensors, gState, nowUs);
  updateEstimatorFromBaro(gSensors, gEst, gState);
}

static void runGpsTask(uint32_t nowUs) {
  lastGpsUs = nowUs;
  updateGps(gSensors, gState, nowUs);
  updateEstimatorFromGps(gSensors, gEst, gState);
}

static void runControlTask(uint32_t nowUs) {
  float dt = (lastCtlUs == 0) ? (1.0f / CONTROL_HZ) : ((nowUs - lastCtlUs) * 1e-6f);
  lastCtlUs = nowUs;

  evaluateFailsafe(gState, gSensors, gCmd, gFail, nowUs);
  computeControl(gState, gSensors, gEst, gCmd, gFail, gOut, dt);
  applyActuatorOutputs(gOut, gState, gFail, nowUs);
}

static void runTelemetryTask(uint32_t nowUs) {
  lastTelUs = nowUs;
  publishTelemetry(gState, gSensors, gEst, gCmd, gOut, gFail, nowUs);
}

static void runCommandTask(uint32_t nowUs) {
  lastCmdUs = nowUs;
  pollCommands(gState, gCmd, nowUs);
  if (USE_NRF24) {
    pollRadio(gState, gCmd, nowUs);
  }
}

void setup() {
  Serial.begin(SERIAL_BAUD);
  delay(BOOT_DELAY_MS);

  initDefaults(gState, gCmd, gOut, gFail);
  initTelemetry();
  initCommands();

  bool sensorsOk = initSensors(gState);
  bool actuatorsOk = initActuators(gState);
  initEstimator(gEst);
  initController(gState);
  initFailsafe(gFail);

  bool radioOk = !USE_NRF24 || initRadio();

  if (!sensorsOk || !actuatorsOk || !radioOk) {
    gState.systemStatus = SYS_DEGRADED;
  }

  printBootSummary(gState);
}

void loop() {
  uint32_t nowUs = micros();

  if (nowUs - lastCmdUs >= CMD_PERIOD_US) {
    runCommandTask(nowUs);
  }
  if (nowUs - lastImuUs >= IMU_PERIOD_US) {
    runImuTask(nowUs);
  }
  if (nowUs - lastBaroUs >= BARO_PERIOD_US) {
    runBaroTask(nowUs);
  }
  if (nowUs - lastGpsUs >= GPS_PERIOD_US) {
    runGpsTask(nowUs);
  }
  if (nowUs - lastCtlUs >= CONTROL_PERIOD_US) {
    runControlTask(nowUs);
  }
  if (nowUs - lastTelUs >= TELEMETRY_PERIOD_US) {
    runTelemetryTask(nowUs);
  }

  if (nowUs - lastHeartbeatUs >= HEARTBEAT_PERIOD_US) {
    lastHeartbeatUs = nowUs;
    gState.loopHeartbeatCount++;
  }
}

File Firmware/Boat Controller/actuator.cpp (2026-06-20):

#include "actuator.h"
#include <Servo.h>
#include "config.h"

static Servo sRudder;
static Servo sEsc;

static int sServoUs = SERVO_US_CENTER;
static int sEscUs = ESC_US_MIN;
static uint32_t sArmStartedMs = 0;

static int clampi(int v, int lo, int hi) {
  return (v < lo) ? lo : ((v > hi) ? hi : v);
}

static float clampf(float v, float lo, float hi) {
  return (v < lo) ? lo : ((v > hi) ? hi : v);
}

static int slewStep(int current, int target, int maxDelta) {
  int delta = target - current;
  if (delta > maxDelta) return current + maxDelta;
  if (delta < -maxDelta) return current - maxDelta;
  return target;
}

bool initActuators(BoatState &state) {
  sRudder.attach(PIN_SERVO_SIGNAL, SERVO_US_MIN, SERVO_US_MAX);
  sEsc.attach(PIN_ESC_SIGNAL, ESC_US_MIN, ESC_US_MAX);

  sServoUs = SERVO_US_CENTER;
  sEscUs = ESC_US_MIN;
  sRudder.writeMicroseconds(sServoUs);
  sEsc.writeMicroseconds(sEscUs);

  state.armState = ARM_DISARMED;
  return true;
}

void applyActuatorOutputs(const ControlOutput &out, BoatState &state, const FailsafeState &fail, uint32_t nowUs) {
  float steer = clampf(out.steeringNorm, -1.0f, 1.0f);
  float throttle = clampf(out.throttleNorm, 0.0f, 1.0f);

  if (fail.active) {
    steer = 0.0f;
    throttle = 0.0f;
    state.armState = ARM_DISARMED;
  }

  if (state.armState == ARM_DISARMED) {
    if (throttle <= 0.01f) {
      state.armState = ARM_ARMING;
      sArmStartedMs = millis();
    } else {
      throttle = 0.0f;
    }
  }

  if (state.armState == ARM_ARMING) {
    throttle = 0.0f;
    if ((millis() - sArmStartedMs) >= ESC_ARM_TIME_MS) {
      state.armState = ARM_ARMED;
    }
  }

  int targetServo = SERVO_US_CENTER + static_cast<int>(steer * SERVO_MAX_DEFLECT_US);
  targetServo = clampi(targetServo, SERVO_US_MIN, SERVO_US_MAX);

  int targetEsc = ESC_US_IDLE + static_cast<int>(throttle * (ESC_US_MAX - ESC_US_IDLE));
  targetEsc = clampi(targetEsc, ESC_US_MIN, ESC_US_MAX);
  if (state.armState != ARM_ARMED) {
    targetEsc = ESC_ARM_US;
  }

  sServoUs = slewStep(sServoUs, targetServo, SERVO_MAX_SLEW_US_PER_TICK);
  sEscUs = slewStep(sEscUs, targetEsc, ESC_MAX_SLEW_US_PER_TICK);

  sRudder.writeMicroseconds(sServoUs);
  sEsc.writeMicroseconds(sEscUs);

  (void)nowUs;
}
